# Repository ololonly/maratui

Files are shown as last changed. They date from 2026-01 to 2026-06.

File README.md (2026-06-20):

<p align="center">
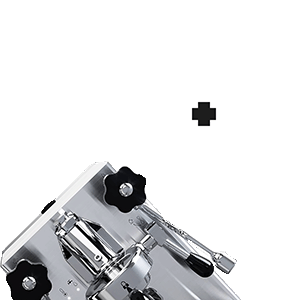
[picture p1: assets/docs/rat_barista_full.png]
MaraTUI — rat barista
    
    <br><br>
    <a href="https://github.com/ratatui/ratatui">
        
    </a>
</p>

# MaraTUI

An embedded Rust TUI application for the **Lelit Mara X** espresso machine. Runs on an **ESP32** microcontroller driving an **ILI9341 320×240 display** over SPI, reads machine telemetry over UART, and publishes events to MQTT. Includes a host simulator mode for UI development without any hardware.

## Screenshots

| Loading | Dashboard | Debug |
|---|---|---|
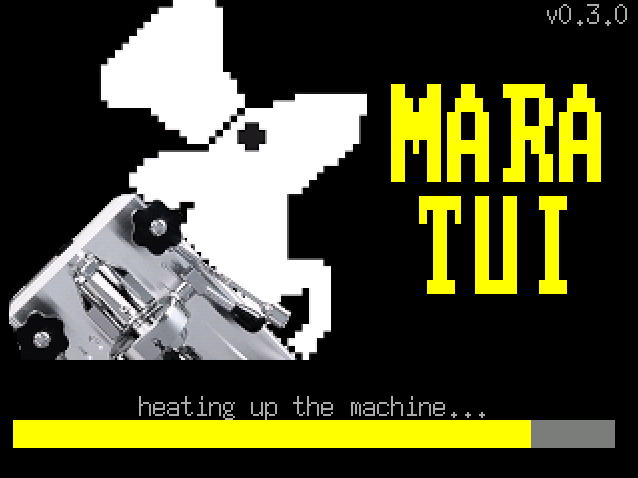
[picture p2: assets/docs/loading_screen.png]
Loading
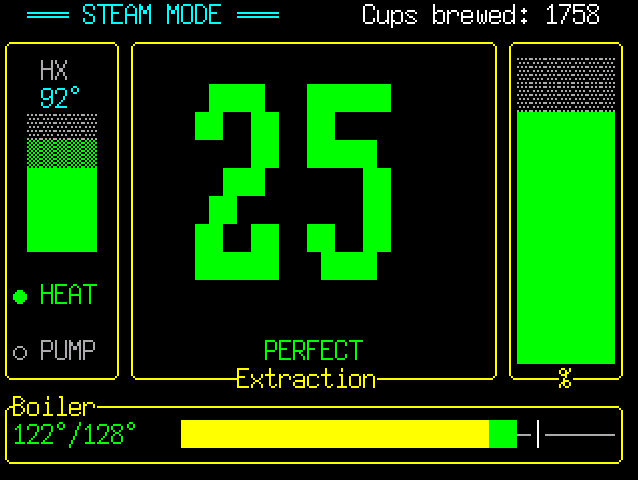
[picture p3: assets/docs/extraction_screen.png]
Dashboard
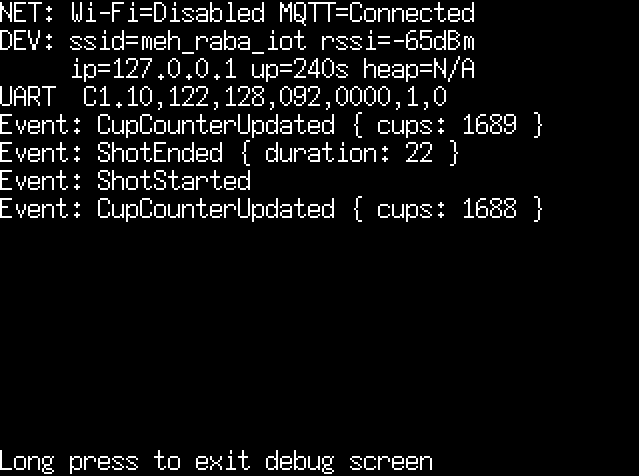
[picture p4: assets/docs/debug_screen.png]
Debug
|  |  |  |

## Screens

Navigation cycles between two main screens with a button press. The Debug screen is a hidden overlay.

### Dashboard

The primary screen. Shows all real-time machine data:

- **Mode banner** — COFFEE / STEAM / OFFLINE, color-coded
- **Boiler gauge** — current vs. target temperature with warm→ready color zones and a target marker
- **HX column** — heat-exchanger temperature with a vertical mini-gauge; ideal zone (90–95°C) is always visible
- **HEAT / PUMP indicators** — live status dots
- **Extraction timer** — large countdown in seconds, color shifts white→green→yellow as the shot progresses
- **Shot quality label** — post-extraction assessment (UNDEREXTRACTED / GOOD / PERFECT / LONG SHOT / BLONDING) shown after the pump stops
- **Cup counter** — total shots brewed, received via MQTT

### Graphs

Temperature history chart over a **5-minute rolling window** sampled at 1 Hz:

- Boiler current temperature (yellow)
- Boiler target temperature (red)
- HX temperature (blue)

### Debug (hidden overlay)

Accessible via long press. Shows Wi-Fi and MQTT connection statuses, device info (SSID, RSSI, IP, uptime, free heap), live raw UART frame with activity indicator, and the last 10 telemetry events.

## Getting Started

### Simulator

The simulator runs on your host machine using SDL2 for display emulation — no ESP32 needed.

**Prerequisites:** install SDL2 development libraries for your OS ([installation guide](https://docs.rs/crate/sdl2/latest/source/README.md)).

```bash
make sim          # auto-detects OS
```

Or use platform-specific cargo aliases:

| OS | Command |
|---|---|
| Linux | `cargo sim` |
| macOS | `cargo simmac` |
| Windows | `cargo simwin` |

**Keyboard controls:**

| Key | Action |
|---|---|
| Right / Left | Toggle Dashboard ↔ Graphs |
| D | Toggle Debug overlay |
| Up | Inject pump-on debug frame |
| Down | Inject normal debug frame |
| Space | Inject no-water debug frame |
| M | Publish manual MQTT event |

### Device (ESP32)

**Prerequisites:** Rust with the `esp` toolchain channel (pinned in `rust-toolchain.toml`).

```bash
cargo run --release
```

Uses `espflash flash --monitor` as the runner. On startup the firmware:

1. Connects to Wi-Fi using embedded credentials
2. Starts the MQTT client and subscribes to `<prefix>/cup_counter`
3. Streams telemetry to `<prefix>/telemetry` (~1 Hz)
4. Publishes events (shot start/end, water refill, mode change) to `<prefix>/events`
5. Publishes device status (IP, RSSI, uptime, heap) to `<prefix>/status`

## Configuration

Copy `.env.example` to `.env` (git-ignored) and fill in your values:

```bash
cp .env.example .env
```

| Variable | Description |
|---|---|
| `MARATUI_WIFI_SSID` / `_PASSWORD` | Wi-Fi credentials (device build only) |
| `MARATUI_MQTT_ENABLED` | Set `true` to enable MQTT publishing |
| `MARATUI_MQTT_URL` | Broker URL, e.g. `mqtt://192.168.1.x:1883` |
| `MARATUI_MQTT_CLIENT_ID` | Unique client identifier |
| `MARATUI_MQTT_TOPIC_PREFIX` | Topic namespace prefix (default: `mara`) |

> [!NOTE]
> On the ESP32 build (`device` feature), `.env` is parsed by `build.rs` and values are embedded at compile time. On the simulator (`simulator` feature), env values are read at runtime and Wi-Fi is skipped — host networking is used directly for MQTT.

> [!WARNING]
> Wi-Fi and MQTT credentials are stored as plaintext `&'static str` in the flash image. Rotate credentials if the device is shared or its firmware is distributed. See the [Security Considerations](#security-considerations) section below.

## Home Assistant Integration

Build with `--features home-assistant` to enable MQTT Discovery publishing directly from the firmware — no Node-RED or other bridge required. On every MQTT connect, retained discovery configs are published and entities appear in Home Assistant automatically.

```bash
cargo run --release --features home-assistant   # flash
make sim-ha                                      # simulator
```

See [docs/home-assistant.md](docs/home-assistant.md) for the full entity list, MQTT topic reference, and cup counter setup.

## Hardware

Target board: **ESP32 Type-C** with an external **ILI9341** 240×320 TFT display connected over SPI. There is a single physical button.

| Press | Action |
|---|---|
| Short | Toggle Dashboard ↔ Graphs |
| Short (on loading)| Toggle display backlight |
| Long | Enter / exit Debug overlay |

See [`hardware/`](hardware/) for the KiCad project, PCB renders, Gerber files, and full ESP32 pinout and display wiring.

## Security Considerations

- **Credentials in flash** — Wi-Fi and MQTT credentials are embedded at compile time and extractable from the flash image with standard tools (`strings`, `binwalk`). Rotate if the device is shared.
- **Default broker is public** — `mqtt://broker.emqx.io:1883` is a free public broker with no access control. Set a private broker with authentication before deploying.
- **No TLS** — traffic is plaintext TCP. Switch to `mqtts://` and configure a CA certificate for production use.
- **Open Wi-Fi fallback** — if `MARATUI_WIFI_PASSWORD` is empty, `AuthMethod::None` is used (no encryption). A startup `warn!` names the SSID to make this explicit.

## Roadmap

- Offline mode using NVS storage

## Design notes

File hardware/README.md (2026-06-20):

# MaraTUI PCB

Custom ESP32 controller board for the [Lelit Mara X](https://lelitcoffee.com/product/mara-x/) espresso machine.

## PCB Renders

| Front | Back |
|:-----:|:----:|
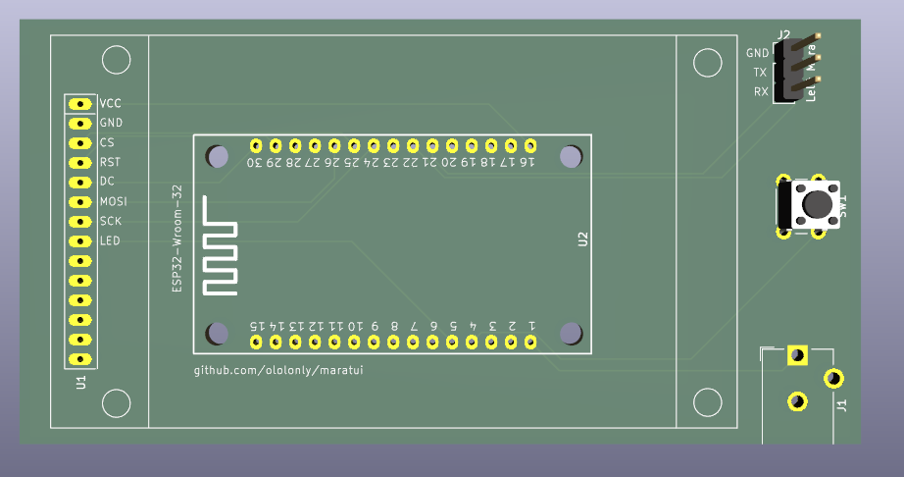
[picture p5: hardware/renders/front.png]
PCB front
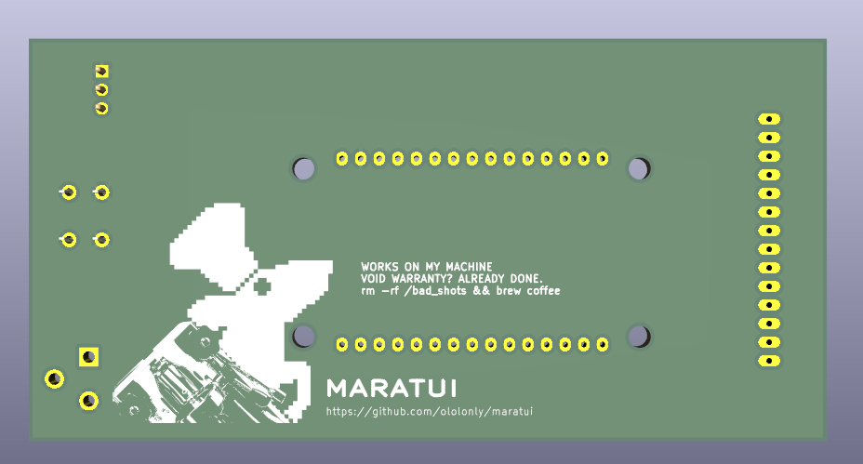
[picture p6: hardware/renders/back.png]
PCB back
|  |  |

## Components

| Ref | Part | Link |
|-----|---|---|
| U1 | ILI9341 2.8" SPI TFT with touch | [Amazon TR](https://www.amazon.com.tr/2-8in%C3%A7-SPI-Dokunmatik-Ekran-Mod%C3%BCl%C3%BC/dp/B0GWFFJBZN) |
| U2 | ESP32-WROOM-32 | [Amazon TR](https://www.amazon.com.tr/ESP32-Wroom-32-Wifi-Bluetooth-Geli%C5%9Ftirme-Kart%C4%B1/dp/B0BT7SW1LF) |
| SW1 | Tactile switch | |
| J1 | Barrel jack (power) | |
| J2 | 3-pin connector (GND + UART) | |

## Wiring

### SPI Display (ILI9341)

| Display Pin | ESP32 GPIO | Notes |
|---|---|---|
| SCK / CLK | GPIO18 | VSPI CLK |
| SDA / MOSI  | GPIO21 | VSPI MOSI |
| DC / RS | GPIO23 | Data/Command select |
| CS | GPIO19 | Chip Select |
| RST / RESET | GPIO22 | Hardware reset |
| LED / BLK | GPIO14 | Backlight (HIGH = on) |
| VCC | 3.3V | |
| GND | GND | |

### UART (Lelit Mara X telemetry)

| Function | ESP32 GPIO | Notes |
|---|---|---|
| TX | GPIO17 | UART1 TX |
| RX | GPIO16 | UART1 RX |

### Button

| Button | ESP32 GPIO | Notes |
|---|---|---|
| SW1 | GPIO12 | Internal pull-up enabled |

Button connects GPIO to **GND** via a tactile switch (active LOW, falling-edge detection).

- Short press (< 500 ms): cycle screens (Dashboard ↔ Graphs)
- Long press (≥ 500 ms): toggle Debug screen

## Custom Libraries

Non-standard components are bundled in `lib/` so the project opens without missing library errors on any machine.

| File | Description |
|---|---|
| `lib/symbols/esp32_30pin.kicad_sym` | ESP32-WROOM-32 symbol |
| `lib/symbols/tft_320x240.kicad_sym` | ILI9341 320×240 symbol |
| `lib/footprints/maratui.pretty/ESP32_30pin.kicad_mod` | ESP32 footprint |
| `lib/footprints/maratui.pretty/TFT-320x240.kicad_mod` | TFT display footprint |

## Manufacturing

Gerber files for fabrication: `gerbers/maratui-v1.zip`

Tested with JLCPCB default 2-layer settings.

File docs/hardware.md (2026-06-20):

# Hardware Wiring

Target board: **ESP32 Type-C** (generic) with external **ILI9341** 240x320 TFT display.

| ESP32 Type-C | ILI9341 Display |
|:---:|:---:|
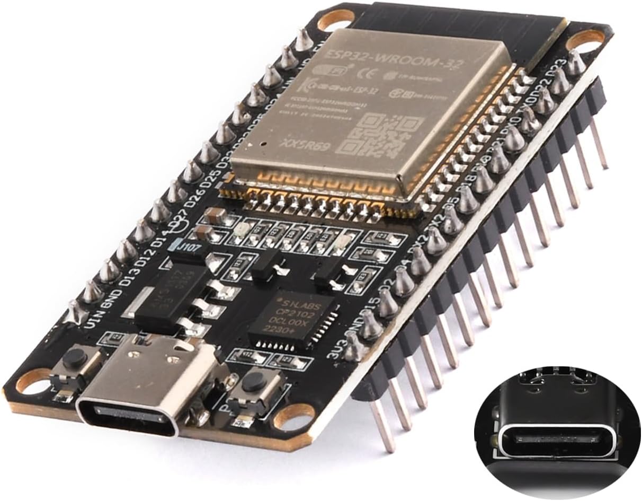
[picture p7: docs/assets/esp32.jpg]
ESP32
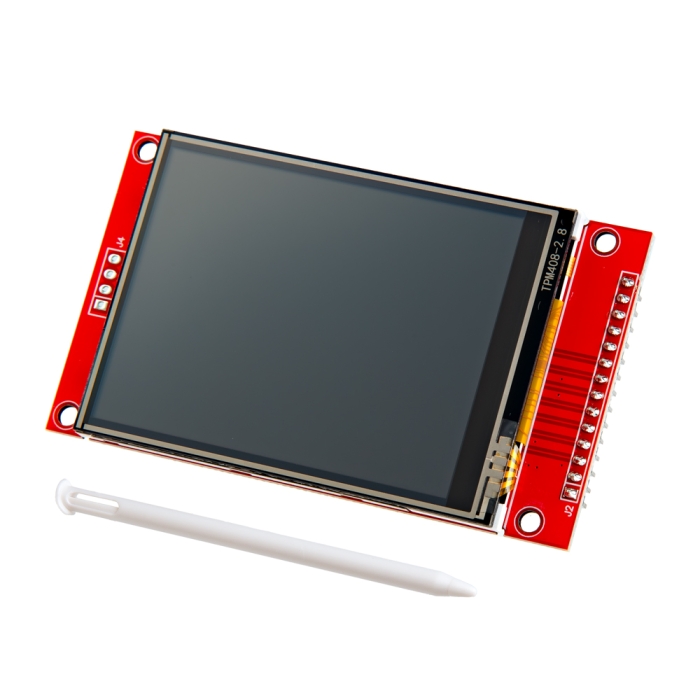
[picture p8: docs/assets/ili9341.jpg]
ILI9341
|  |  |

## Pinout

### SPI Display (ILI9341)

| Display Pin | ESP32 GPIO | Notes |
|---|---|---|
| SCK / CLK | GPIO18 | VSPI CLK |
| SDA / MOSI  | GPIO21 | VSPI MOSI |
| DC / RS | GPIO23 | Data/Command select |
| CS | GPIO19 | Chip Select |
| RST / RESET | GPIO22 | Hardware reset |
| LED / BLK | GPIO14 | Backlight (driven HIGH = on) |
| VCC | 3.3V | |
| GND | GND | |

### UART (Lelit Mara X telemetry)

| Function | ESP32 GPIO | Notes |
|---|---|---|
| TX | GPIO17 | UART1 TX |
| RX | GPIO16 | UART1 RX |

### Button

| Button | ESP32 GPIO | Notes |
|---|---|---|
| Button 1 | GPIO12 | Internal pull-up enabled |

Button connects GPIO to **GND** through a tactile switch (active LOW, NegEdge detection).
Short press (< 500 ms): toggle Dashboard ↔ Graphs. Long press (≥ 500 ms): toggle Debug screen.

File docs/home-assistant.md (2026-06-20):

# Home Assistant Integration

MaraTUI can publish Home Assistant MQTT Discovery configs directly from the firmware — no Node-RED or any other bridge required.

## Architecture

```
ESP32 (MaraTUI)
    │  UART telemetry
    │  MQTT (homeassistant/# discovery + state)
    └─► MQTT broker ──────────────────────────────► Home Assistant
                                                          │
                                                    sensors / binary sensors
                                                    auto-registered via Discovery
```

On connect, the firmware publishes retained discovery configs to `homeassistant/sensor/maratui_*/config` and `homeassistant/binary_sensor/maratui_*/config`. Home Assistant picks them up automatically — no manual YAML needed.

## Prerequisites

- MQTT broker reachable by both the ESP32 and Home Assistant (e.g. Mosquitto on the same host)
- Home Assistant with the MQTT integration enabled (Settings → Devices & Services → MQTT)

## Enabling HA Discovery

Add `--features home-assistant` to your build command:

**Flash to device:**
```bash
cargo run --release --features home-assistant
# or
make flash-ha
```

**Run the simulator:**
```bash
cargo simha          # Linux
cargo simmacHA       # macOS
make sim-ha          # auto-detects OS
```

That's it — on first MQTT connect the firmware publishes all discovery configs, and entities appear in HA within seconds.

## MQTT Topics Published by MaraTUI

### `<prefix>/telemetry` — ~1 Hz JSON frame

```json
{
  "mode": "Coffee",
  "sw": "1.10",
  "boiler_now_c": 93,
  "boiler_target_c": 94,
  "hx_now_c": 91,
  "boost_countdown_s": 0,
  "heating_on": false,
  "pump_on": false,
  "no_water_code": null
}
```

### `<prefix>/events` — on-change JSON events

| `type` | Extra fields | Description |
|---|---|---|
| `shot_started` | — | Pump just turned on |
| `shot_ended` | `duration` (int, seconds) | Pump turned off; duration of the shot |
| `shot_aborted` | `duration` (int, seconds) | Pump ran < 10 s (rinse / pre-heat kick) |
| `water_refill_needed` | `code` (int) | Water low detected |
| `water_refill_cleared` | — | Water low cleared |
| `mode_changed` | `from`, `to` (strings) | Machine mode transition |

### `<prefix>/status` — periodic device info (~30 s)

```json
{
  "uptime_s": 3600,
  "wifi_ssid": "MyNetwork",
  "wifi_rssi": -62,
  "ip": "192.168.1.42",
  "free_heap_b": 180000,
  "last_telemetry_age_s": 1
}
```

The topic prefix defaults to `mara` and is configured via `MARATUI_MQTT_TOPIC_PREFIX` in `.env`.

## Home Assistant Entities

All entities appear under a single device named **Lelit Mara X**.

### Sensors

| Entity | Unit | Notes |
|---|---|---|
| Mode | — | Operating mode |
| Firmware Version | — | Diagnostic |
| Boiler Temperature | °C | `device_class: temperature` |
| Boiler Target | °C | `device_class: temperature` |
| HX Temperature | °C | `device_class: temperature` |
| Last Extraction Duration | s | Retained; updated on shot end |
| Extraction Timer | s | Live counter during shot |
| Time Since Last Shot | min | Minutes since pump last stopped |
| Cup Counter | — | See cup counter setup below |
| Uptime | min | Diagnostic |
| Wi-Fi RSSI | dBm | Diagnostic |
| Wi-Fi SSID | — | Diagnostic |
| IP Address | — | Diagnostic |
| Free Heap | kB | Diagnostic |
| Telemetry Age | s | Diagnostic |

### Binary Sensors

| Entity | Notes |
|---|---|
| Heating | `device_class: heat` |
| Pump Active | On while shot is in progress |
| Water Level Low | `device_class: problem` |

## Cup Counter Setup

The cup counter requires a short one-time setup in Home Assistant. The counter value is stored as an HA helper and published back to the broker so the MaraTUI display stays in sync.

### 1. Create a Counter helper

Settings → Devices & Services → Helpers → **+ Create helper** → **Counter**

- Name: `Mara Shots`
- Entity ID: `counter.coffee_counter` (default)
- Initial value: your current count (or 0)

### 2. Import the automation

Settings → Automations → **+ Create automation** → ⋮ menu → **Edit in YAML**

Paste the contents of `docs/ha-automation.yaml`, save, and enable.

The automation triggers on `mara/events` when `type == shot_ended` and `duration > 20 s`, increments the helper, and publishes the new value to `mara/cup_counter` (retained) so both the HA sensor and the ESP32 display update.

### Cup counter flow

```
MaraTUI → mara/events {"type":"shot_ended","duration":35}
               ↓
         HA automation (ha-automation.yaml)
         duration > 20 s → counter.increment(counter.coffee_counter)
                         → mqtt.publish(mara/cup_counter, retained)
               ↓
         ESP32 subscribes to mara/cup_counter → display updates
         HA sensor maratui_cup_counter reads mara/cup_counter → HA updates
```

## Troubleshooting

**Entities don't appear in HA**
- Check that the MQTT integration is enabled (Settings → Devices & Services → MQTT).
- Confirm the broker MaraTUI connects to is the same one HA uses.
- Subscribe to `homeassistant/#` with `mosquitto_sub -t 'homeassistant/#' -v` to verify discovery configs are arriving.
- Power-cycle or reconnect the ESP32 — discovery configs are re-sent on every MQTT connect.

**Values don't update**
- Confirm the ESP32 is connected to Wi-Fi and MQTT (`MARATUI_MQTT_ENABLED=true` in `.env`).
- Check the MaraTUI Debug screen for UART activity and connection status.
- Subscribe to `mara/#` to see raw messages from the device.

**Topic mismatch**
- If you set `MARATUI_MQTT_TOPIC_PREFIX` to something other than `mara`, update the topics in `docs/ha-automation.yaml` accordingly.

**Cup counter not incrementing**
- Verify the automation is enabled and the trigger topic matches your prefix.
- Check HA automation traces (Settings → Automations → Mara Shot Counter → ⋮ → Traces).

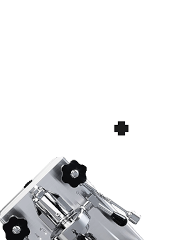
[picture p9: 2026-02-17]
assets/rat_barista.png

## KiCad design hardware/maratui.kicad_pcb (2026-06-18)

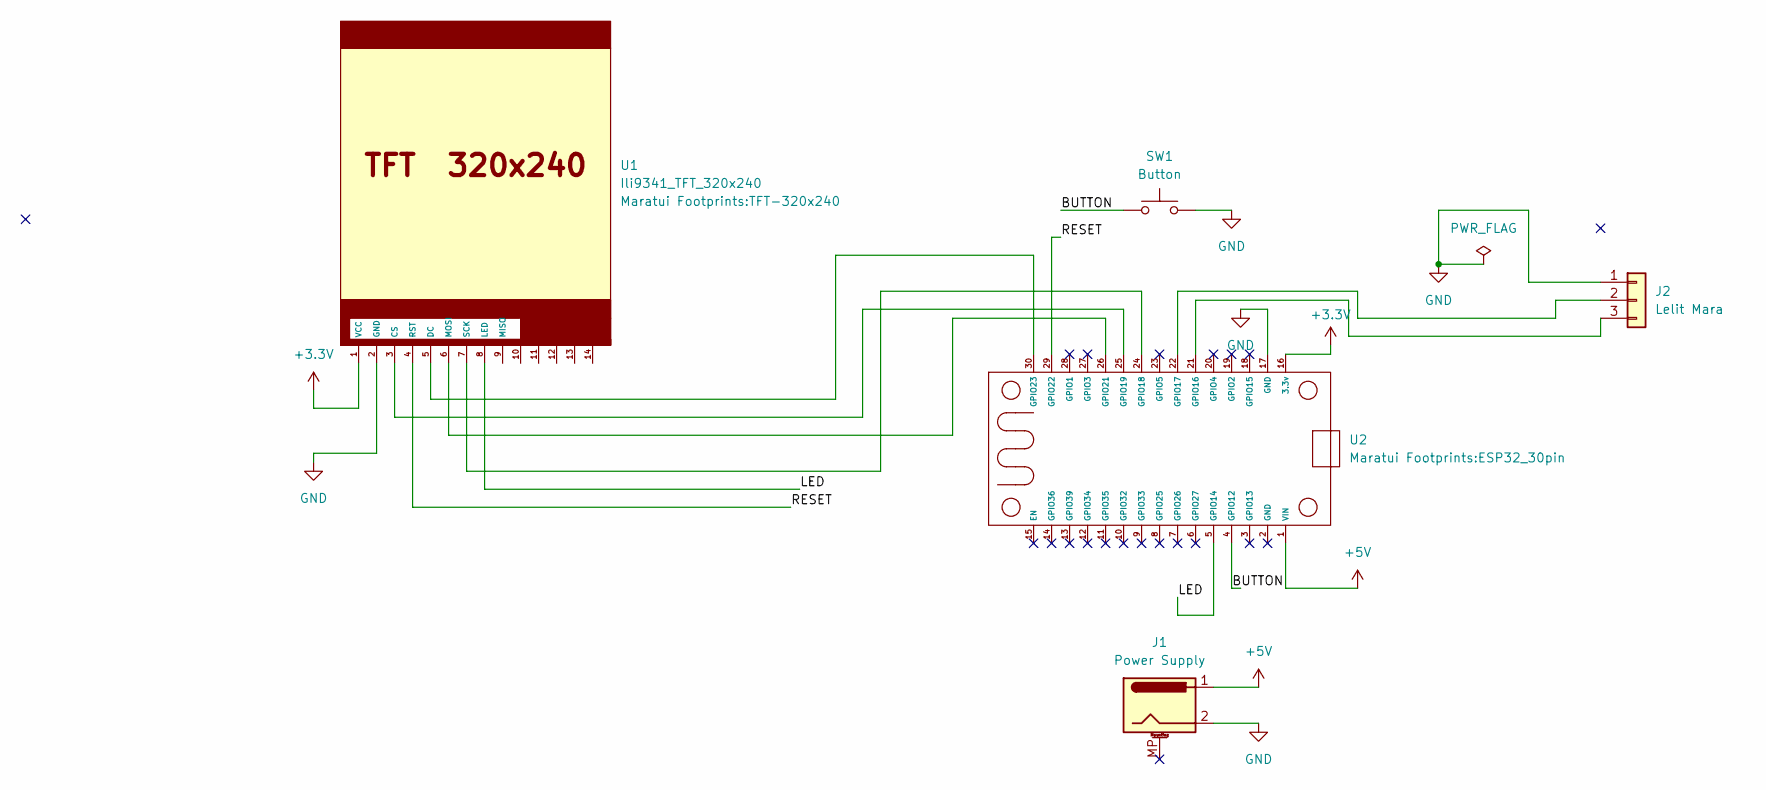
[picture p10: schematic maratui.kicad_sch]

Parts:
J1: Power Supply; BarrelJack_CUI_PJ-102AH_Horizontal
J2: Lelit Mara; PinHeader_1x03_P2.54mm_Vertical
SW1: Button; SW_PUSH_6mm
U1: Ili9341_TFT_320x240; TFT-320x240
U2: ESP32_30pin

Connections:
+3.3V: U1.1 (VCC), U2.16 (3.3v)
+5V: J1.1, U2.1 (VIN)
/BUTTON: SW1.1, U2.4 (GPIO12)
/LED: U1.8 (LED), U2.5 (GPIO14)
/RESET: U1.4 (RST), U2.29 (GPIO22)
GND: J1.2, J2.1, SW1.2, U1.2 (GND), U2.17 (GND)
unnamed: J2.2, U2.22 (GPIO17)
unnamed: J2.3, U2.21 (GPIO16)
unnamed: U1.3 (CS), U2.25 (GPIO19)
unnamed: U1.5 (DC), U2.30 (GPIO23)
unnamed: U1.6 (MOSI), U2.26 (GPIO21)
unnamed: U1.7 (SCK), U2.24 (GPIO18)

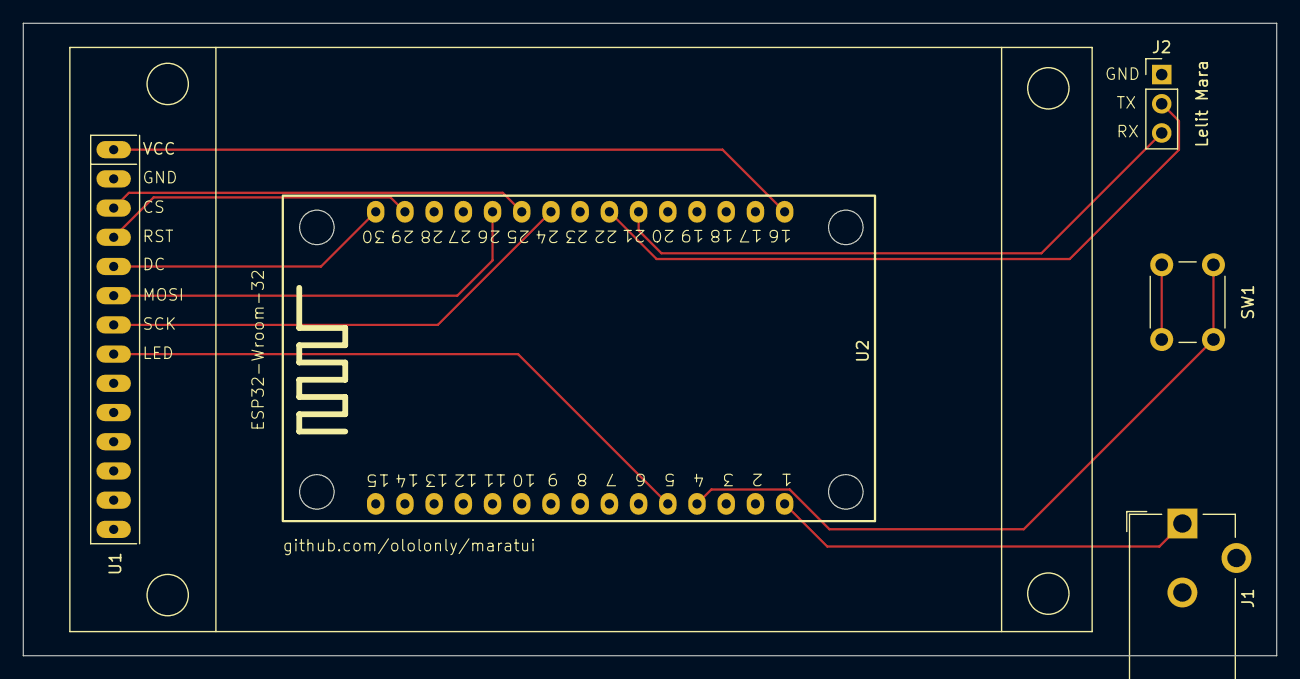
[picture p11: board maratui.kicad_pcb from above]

Board: 2 copper layers, 109.0 x 55.0 mm, 5 parts (0 on the bottom side), 12 nets.

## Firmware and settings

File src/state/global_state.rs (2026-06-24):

use crate::screens::Screen;
use crate::telemetry::MachineState;
use std::{
    collections::VecDeque,
    time::{Duration, Instant},
};

// TODO: if the device is powered directly from the espresso machine, the backlight
// timeout is unnecessary — consider removing BACKLIGHT_TIMEOUT and backlight_should_be_on entirely.
pub const BACKLIGHT_TIMEOUT: Duration = Duration::from_secs(10);

/// How long telemetry may be absent before the machine is considered offline.
///
/// Once this elapses with no UART frame, the UI falls back to the waiting screen and
/// the next frame to arrive starts a fresh session (terminal + graph buffers cleared).
pub const MACHINE_OFFLINE_TIMEOUT: Duration = Duration::from_secs(30);

#[derive(Clone, Debug, Default, PartialEq, Eq)]
pub enum ConnectionStatus {
    Disabled,
    #[default]
    Disconnected,
    Connecting,
    Connected,
    Error(String),
}

#[derive(Clone, Debug)]
pub struct MqttOutboundMessage {
    /// Topic suffix (combined with prefix by publish_mqtt_message) unless `absolute` is true.
    pub topic_suffix: String,
    pub payload: String,
    /// When `true`, the broker should store a retained copy of this message.
    pub retain: bool,
    /// When `true`, `topic_suffix` is used as-is (bypasses prefix construction).
    pub absolute: bool,
}

/// State of the coffee extraction process
#[derive(Clone, Debug, PartialEq, Eq)]
pub enum ExtractionState {
    /// Pump is not running, no extraction in progress
    Idle {
        /// Duration of the last completed extraction
        last_extraction_duration: Option<Duration>,
    },
    /// Pump is running, extraction in progress
    Extracting { started_at: Instant },
}

impl Default for ExtractionState {
    fn default() -> Self {
        Self::Idle {
            last_extraction_duration: None,
        }
    }
}

impl ExtractionState {
    /// Get the duration of the current extraction (if in progress)
    pub fn elapsed(&self) -> Option<Duration> {
        match self {
            ExtractionState::Extracting { started_at } => Some(started_at.elapsed()),
            ExtractionState::Idle { .. } => None,
        }
    }

    /// Check if extraction is currently in progress
    pub fn is_extracting(&self) -> bool {
        matches!(self, ExtractionState::Extracting { .. })
    }

    /// Get the duration of the last completed extraction
    pub fn last_extraction_duration(&self) -> Option<Duration> {
        match self {
            ExtractionState::Idle {
                last_extraction_duration,
            } => *last_extraction_duration,
            ExtractionState::Extracting { .. } => None,
        }
    }
}

/// Board metadata published to MQTT and shown on the Debug screen
#[derive(Clone, Debug, Default, PartialEq, Eq)]
pub struct DeviceInfo {
    pub wifi_ssid: String,
    pub wifi_rssi: Option<i32>,
    pub ip: Option<String>,
    pub uptime_s: u64,
    pub free_heap_b: Option<u32>,
    /// Seconds since the last UART telemetry frame was received
    pub last_telemetry_age_s: Option<u64>,
}

/// Application errors
#[derive(Clone, Debug, PartialEq, Eq)]
pub enum AppError {
    /// Water refill is needed
    WaterRefillNeeded { code: u16 },
    /// Machine is offline
    MachineOffline,
}

impl std::fmt::Display for AppError {
    fn fmt(&self, f: &mut std::fmt::Formatter<'_>) -> std::fmt::Result {
        match self {
            AppError::WaterRefillNeeded { code } => {
                write!(f, "Water refill needed (code: {})", code)
            }
            AppError::MachineOffline => write!(f, "Machine is offline"),
        }
    }
}

/// Global application state
/// Single point of state management for the entire application
#[derive(Debug)]
pub struct GlobalAppState {
    /// Currently displayed screen
    pub current_screen: Screen,
    /// State of the extraction process
    pub extraction_state: ExtractionState,
    /// Machine state (mode, temperatures, pump, etc.)
    pub machine_state: MachineState,
    pub events_log: VecDeque<String>,
    pub wifi_status: ConnectionStatus,
    pub mqtt_status: ConnectionStatus,
    pub cup_counter: Option<u64>,
    pub outbound_mqtt: VecDeque<MqttOutboundMessage>,
    /// Current error (if any)
    pub error: Option<AppError>,
    /// Screen to return to when toggling out of Debug
    pub screen_before_debug: Option<Screen>,
    /// Backlight toggle during the loading phase (short press on/off); ignored after first UART frame
    pub backlight_on: bool,
    /// Last time UART telemetry or a button press was received (for backlight timeout)
    pub last_activity_at: Option<Instant>,
    /// Last time a UART telemetry frame was received (for Debug screen activity marker)
    pub last_uart_frame_at: Option<Instant>,
    /// Time when the last shot ended (pump turned off after a valid extraction)
    pub last_shot_ended_at: Option<Instant>,
    /// MQTT topic prefix (e.g. "mara"), mirrored from AppConfig for use in HA state topics
    pub mqtt_topic_prefix: String,
    /// Board metadata (WiFi RSSI, IP, uptime, free heap)
    pub device_info: DeviceInfo,
    /// Current boot loading stage; `None` before first stage fires, frozen at 100% while waiting for machine
    pub loading_status: Option<(&'static str, u8)>,
    /// Set by the state machine to ask the render loop for a full `terminal.clear()`
    /// (new session, Debug toggle). Drained once per frame via `take_redraw_request`.
    pub needs_terminal_clear: bool,
}

impl Default for GlobalAppState {
    fn default() -> Self {
        Self {
            current_screen: Screen::default(),
            extraction_state: ExtractionState::default(),
            machine_state: MachineState::default(),
            events_log: VecDeque::with_capacity(10),
            wifi_status: ConnectionStatus::default(),
            mqtt_status: ConnectionStatus::default(),
            cup_counter: None,
            outbound_mqtt: VecDeque::with_capacity(32),
            error: None,
            screen_before_debug: None,
            backlight_on: true,
            last_activity_at: None,
            last_uart_frame_at: None,
            last_shot_ended_at: None,
            mqtt_topic_prefix: "mara".to_string(),
            device_info: DeviceInfo::default(),
            loading_status: None,
            needs_terminal_clear: false,
        }
    }
}
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

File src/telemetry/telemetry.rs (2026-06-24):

// src/telemetry.rs
use std::{collections::VecDeque, time::Instant};
use strum::Display;

#[derive(Debug, Display, Default, Clone, Copy, PartialEq, Eq)]
pub enum MachineMode {
    #[strum(to_string = "Coffee")]
    Coffee, // '-' | '+'
    #[strum(to_string = "Steam")]
    SteamS, // 'S'
    #[strum(to_string = "Steam")]
    SteamV, // 'V'
    #[strum(to_string = "Steam")]
    SteamC, // 'C' (as you described)
    #[default]
    Offline, // 'X'
    Unknown(char),
}

impl MachineMode {
    pub fn from_char(c: char) -> Self {
        match c {
            '-' | '+' => MachineMode::Coffee,
            'S' => MachineMode::SteamS,
            'V' => MachineMode::SteamV,
            'C' => MachineMode::SteamC,
            'X' => MachineMode::Offline,
            other => MachineMode::Unknown(other),
        }
    }
}

#[derive(Debug, Default, Clone, PartialEq, Eq)]
pub struct TelemetryFrame {
    pub raw_string: String,
    pub mode: MachineMode,
    pub sw_version: String,           // e.g. "1.10"
    pub boiler_now_c: u16,            // e.g. 37
    pub boiler_target_c: Option<u16>, // Some(138) or None if Lxx
    pub no_water_code: Option<u16>,   // Some(65) if "L65"
    pub hx_now_c: u16,                // e.g. 35
    pub boost_countdown_s: u16,       // e.g. 0000 -> 0
    pub heating_on: bool,             // "1"/"0"
    pub pump_on: bool,                // "1"/"0"
}

impl TelemetryFrame {
    pub fn debug_frame() -> Self {
        Self {
            raw_string: "C1.10,122,128,092,0000,1,0".to_string(),
            mode: MachineMode::SteamC,
            sw_version: "1.10".to_string(),
            boiler_now_c: 122,
            boiler_target_c: Some(128),
            hx_now_c: 92,
            boost_countdown_s: 0,
            heating_on: true,
            pump_on: false,
            no_water_code: None,
        }
    }

    pub fn debug_pump_on_frame() -> Self {
        Self {
            raw_string: "C1.10,120,138,090,0000,1,1".to_string(),
            mode: MachineMode::SteamC,
            sw_version: "1.10".to_string(),
            boiler_now_c: 120,
            boiler_target_c: Some(138),
            hx_now_c: 90,
            boost_countdown_s: 0,
            heating_on: true,
            pump_on: true,
            no_water_code: None,
        }
    }

    pub fn debug_no_water_frame() -> Self {
        Self {
            raw_string: "C1.10,122,L65,085,0000,0,0".to_string(),
            mode: MachineMode::Coffee,
            sw_version: "1.10".to_string(),
            boiler_now_c: 122,
            boiler_target_c: None,
            hx_now_c: 85,
            boost_countdown_s: 0,
            heating_on: false,
            pump_on: false,
            no_water_code: Some(65),
        }
    }
}

#[derive(Debug, Clone, PartialEq, Eq)]
pub enum ParseError {
    Empty,
    BadPrefix,
    WrongFieldCount { got: usize, expected: usize },
    BadNumber { field: &'static str, value: String },
    BadBool { field: &'static str, value: String },
}

/// Parses UART line format:
/// <Mode><Version>,<boiler_now>,<boiler_target_or_Lxx>,<hx_now>,<boost>,<heating>,<pump>
/// Examples:
/// - C1.10,037,138,035,0000,0,1
/// - C1.10,037,L65,035,0000,0,0   (no water)
/// - +1.10,089,P75,067,0000,0,0   (P-prefix seen at cold startup in xmode_coffee; semantics TBD)
pub fn parse_uart_line(line: &str) -> Result<TelemetryFrame, ParseError> {
    let s = line.trim();
    if s.is_empty() {
        return Err(ParseError::Empty);
    }

    // First char is the machine mode
    let mut chars = s.chars();
    let mode_char = chars.next().ok_or(ParseError::Empty)?;
    let mode = MachineMode::from_char(mode_char);

    // Until the first comma is a software version (e.g. "1.10")
    let rest = &s[mode_char.len_utf8()..];
    let comma_pos = rest.find(',').ok_or(ParseError::BadPrefix)?;
    let sw_version = rest[..comma_pos].to_string();

    let after = &rest[comma_pos + 1..];
    let parts: Vec<&str> = after.split(',').collect();

    // Expected 6 fields after version:
    // boiler_now, boiler_target_or_Lxx, hx_now, boost, heating, pump
    if parts.len() != 6 {
        return Err(ParseError::WrongFieldCount {
            got: parts.len(),
            expected: 6,
        });
    }

    let boiler_now_c = parse_u16(parts[0], "boiler_now_c")?;

    let (boiler_target_c, no_water_code) = {
        let t = parts[1].trim();
        if let Some(code) = t.strip_prefix('L') {
            let code = parse_u16(code, "no_water_code")?;
            (None, Some(code))
        } else if t.starts_with(|c: char| c.is_ascii_alphabetic()) {
            // Non-numeric prefix other than 'L' — observed as "Pxx" at cold startup in xmode_coffee.
            // Exact semantics are still under investigation (possibly power-up / initial-heating phase).
            // Accepted without error; boiler_target treated as unknown until the frame normalises.
            (None, None)
        } else {
            let target = parse_u16(t, "boiler_target_c")?;
            (Some(target), None)
        }
    };

    let hx_now_c = parse_u16(parts[2], "hx_now_c")?;
    let boost_countdown_s = parse_u16(parts[3], "boost_countdown_s")?;
    let heating_on = parse_bool01(parts[4], "heating_on")?;
    let pump_on = parse_bool01(parts[5], "pump_on")?;

    let raw_string = line.to_string();

    Ok(TelemetryFrame {
        raw_string,
        mode,
        sw_version,
        boiler_now_c,
        boiler_target_c,
        no_water_code,
        hx_now_c,
        boost_countdown_s,
        heating_on,
        pump_on,
    })
}

fn parse_u16(s: &str, field: &'static str) -> Result<u16, ParseError> {
    let t = s.trim();
    t.parse::<u16>().map_err(|_| ParseError::BadNumber {
        field,
        value: t.to_string(),
    })
}

fn parse_bool01(s: &str, field: &'static str) -> Result<bool, ParseError> {
    match s.trim() {
        "0" => Ok(false),
        "1" => Ok(true),
        other => Err(ParseError::BadBool {
            field,
            value: other.to_string(),
        }),
    }
}

const MIN_SHOT_SECS: u64 = 15;

/// High-level events derived from telemetry stream.
/// These are perfect triggers for MQTT "events" topics and for UI notifications.
#[derive(Debug, Clone, PartialEq, Eq)]
pub enum AppEvent {
    /// Pump transitioned from OFF -> ON.
    ShotStarted,

    /// Pump transitioned from ON -> OFF, with total ON duration.
    ShotEnded { duration: u64 },

    /// Pump ran for less than MIN_SHOT_SECS (rinsing / post-heat pump kick).
    ShotAborted { duration: u64 },

    /// No-water condition appeared (None -> Some(code)) or code changed.
    WaterRefillNeeded { code: u16 },

    /// No-water condition cleared (Some -> None).
    WaterRefillCleared,

    /// Mode changed (e.g. Coffee -> Steam, etc.).
    ModeChanged { from: MachineMode, to: MachineMode },
}
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

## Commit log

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2026-01-23 feat(logging): add logging support and improve UART handling
    - Integrated `log` crate for enhanced logging throughout the application.
    - Updated UART initialization to use UART1 instead of UART2, with improved error handling and logging.
    - Refactored `UartReader` to include non-blocking read checks and better buffer management.
    - Enhanced telemetry update logic in `run_app` to reduce load and prevent watchdog timeouts.
    [setup.rs, uart_reader.rs]
2026-01-23 refactor(run_app): simplify UI drawing logic and remove frame counter condition
    - Removed the conditional frame drawing to allow the UI to be drawn on every iteration, improving responsiveness.
    - Maintained a delay to prevent watchdog timeouts and ensure other tasks can run effectively.
    [setup.rs]
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2026-01-28 trying to impement ili9341 display support. extra code commented. just trying to run w/o alloc error
    [setup.rs]
2026-01-28 refactor: update rat and screen modules to use ratatui directly
    - Replaced mousefood crate imports with direct imports from ratatui for Frame, Buffer, Layout, and other components.
    - Added a new constructor method for the Rat struct.
    - Updated the rendering logic to utilize the new Line type from ratatui for text handling.
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2026-01-30 feat(build): enhance build script for ESP32 and add feature flags
    - Updated `build.rs` to check for simulator and device features, providing clearer error messages for simulator usage.
    - Modified `Cargo.toml` to include feature flags for device and simulator builds, improving build flexibility.
    - Updated dependencies in `Cargo.lock` to include new packages and versions, ensuring compatibility with the latest features.
    [setup.rs]
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2026-02-02 fix(simulator): use debug telemetry frame on startup
    [setup.rs]
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2026-02-03 refactor(state): migrate to centralized state management with FSM
    Replace distributed state management with a centralized GlobalAppState and
    AppStateMachine. Move brew timer logic into extraction state tracking within
    the state machine. Update all screen renderers to accept state as a parameter
    instead of managing their own state.
    - Remove BrewTimer struct and integrate timing into ExtractionState
    - Create new state module with GlobalAppState and AppStateMachine
    - Update Board trait to pass GlobalAppState to render methods
    - Simplify screen components (Dashboard, Debug, Graphs, Rat) to stateless
    renderers
    - Refactor telemetry event handling to work with centralized state
    - Update simulato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
    [app.rs, debug.rs, fsm.rs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]
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2026-02-09 feat(state): add event log and frame ownership
    Move latest telemetry frame ownership into `machine_state` and add a
    bounded `events_log` to global app state for recent FSM activity.
    Update dashboard and debug screens to read from `machine_state.last_frame`,
    render an extraction timer block, and show UART plus recent events.
    Make UART parsing resilient by handling parse errors without panicking,
    and align telemetry debug frames/defaults with `no_water_code: None`.
    BREAKING CHANGE: remove `GlobalAppState.last_telemetry`; use
    `GlobalAppState.machine_state.last_frame` instead
    [debug.rs, fsm.rs, global_state.rs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]
2026-02-09 feat(ui): show no-water status in simulator
    Add a dedicated debug telemetry frame for the no-water condition and
    map it to the Space key in the simulator so the state can be exercised
    interactively.
    Update the rat status panel to display a context-aware message when a
    water refill error is present, while keeping the default coffee prompt.
    Fix event log trimming to drop the oldest entry instead of the newest
    one when the log exceeds its size limit.
    [fsm.rs, telemetry.rs]
2026-02-10 build(deps): bump mousefood to 0.4.0
    update the mousefood crate version and align rat screen code with
    current usage by removing unused text imports and icon area binding
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2026-02-11 feat(ui): render rat image directly on display
    replace the ratatui qoi widget path with embedded-graphics image
    rendering from a raw rgb565 asset on the display backend. call image
    rendering in both hardware and simulator loops, and clear the terminal
    on button-driven screen changes to prevent stale artifacts.
    remove the tinyqoi dependency and delete the qoi widget module.
    BREAKING CHANGE: MaraUiApp now requires a render_image method in trait
    implementations
    [app.rs, setup.rs]
2026-02-11 fix: move ifeq directives to top level in Makefile
    ifeq/else/endif are Make directives, not shell commands — they must
    not be indented as recipe lines. Use a variable instead.
    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
2026-02-11 fix(setup): use half-duplex SPI for ili9341
    Set the SPI device config to half-duplex and use an explicit
    Hertz baudrate value before converting into the driver config.
    This aligns setup with the display bus communication mode.
    [setup.rs]
2026-02-11 feat(ui): show thirsty rat on water refill error
    Render a dedicated thirsty rat sprite when the app state reports
    `WaterRefillNeeded` so the dashboard communicates the condition
    visually.
    Add the new thirsty image assets and keep the default barista rat for
    all other states.
    [app.rs]
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2026-02-11 feat(ui): plot live boiler and hx temperatures
    replace graph demo data with telemetry-backed time series for current
    boiler, target boiler, and hx temperatures. add rolling buffers to
    machine state and update them on each telemetry frame to keep roughly
    the last 5 minutes of data for charting.
    update chart axes and legend placement to better match the new live
    temperature ranges and timeline labels.
    [fsm.rs, telemetry.rs]
2026-02-11 feat(ui): add shortcut to open debug screen
    Introduce a dedicated DebugScreen app event and handle it in the
    state machine so pressing both buttons jumps directly to the debug
    screen.
    Update screen navigation to exclude Debug from normal next/previous
    rotation, and add a simulator keybinding (`D`) to trigger the same
    behavior for easier testing.
    [fsm.rs, setup.rs]
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2026-02-16 fix(mqtt): wait for broker connect before subscribe
    Delay topic subscription until a Connected event is received to avoid
    subscribing before the client session is ready.
    Also configure the STA netif with a DHCP hostname (`maratui`) by
    wrapping Wi-Fi with explicit netif configuration.
    [setup.rs]
2026-02-16 fix(ui): update temperature chart labels
    Rename the chart title to "Temperatures" and remove the y-axis
    title to avoid redundant labeling in the graph UI.
2026-02-17 feat(ui): add startup loading screen and new assets
    Display a full-screen loading image during hardware setup and clear the
    screen before entering the main loop to avoid stale frames.
    Update barista image assets, switch the README preview to the new full
    artwork, and move the in-app barista render to the top to fit the new
    image composition.
    [app.rs, setup.rs]
2026-02-17 fix(ui): clear display via terminal backend
    Ensure cleanup uses the same display instance managed by the
    terminal before entering the main loop
    [setup.rs]
2026-03-03 fix(hardware): align esp32 pin mapping and io setup
    [setup.rs]
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2026-04-27 feat(ui): add auto-return to previous screen after extraction with backlight timeout
    Implement automatic screen navigation and backlight management based on user activity:
    - Auto-switch to Dashboard when extraction starts, saving the previous screen
    - Auto-return to saved screen 5 seconds after extraction ends
    - Manual navigation during cooldown cancels the scheduled return
    - Backlight turns off after 10 seconds of inactivity (no telemetry or button presses)
    - Track activity timestamps for both telemetry updates and button presses
    - Clear terminal when transitioning away from Main screen to prevent artifacts
    - Fix shot duration display from milliseconds to seconds
    Add new trait methods to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
    [app.rs, fsm.rs, global_state.rs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]
2026-04-27 refactor(ui): redesign dashboard with improved layout and visual feedback
    - Reorganize layout into banner, content columns, and bottom gauge
    - Add horizontal boiler temperature gauge with color-coded status
    - Add vertical shot progress gauge with time-based quality indicators
    - Add mode-specific banner with color coding (coffee/steam/offline)
    - Add real-time status indicators for heating and pump
    - Implement post-shot quality labels (too short, perfect, etc.)
    - Use progressive color feedback during extraction (white → green → yellow)
    - Simplify information display with better use of space
    - Remove redundant blocks and improve visual hierarchy
2026-04-27 refactor(ui): replace boiler gauge with custom temperature bar and refine shot quality feedback
    Replace the generic Gauge widget with a custom temperature bar featuring:
    - Absolute temperature scale (0-150°C)
    - Color zones: yellow (warming) → green (ready at 90%)
    - Target temperature marker
    - Compact label format showing current/target temps
    Refine extraction timer quality assessment:
    - Adjust shot timing sweet spot to 25-27s for "PERFECT"
    - Expand quality labels: "FAST FLOW", "GOOD", "LONG SHOT", "BLONDING"
    - Update live extraction green zone to 20-27s
    - Pin post-shot assessment label to bottom of timer block
    Simplify layout:
    - Switch shot gauge to rule-of-thirds (1:3:1) proportional l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
2026-04-27 feat(ui): add connecting screen and block navigation before telemetry
    Add a new Connecting screen that displays until the first UART telemetry
    frame arrives. Block all navigation (except to Debug screen) until
    telemetry is received to prevent rendering errors from missing data.
    Changes include:
    - New Connecting screen module and render logic
    - Navigation blocking in button handler until first frame
    - Debug screen toggle functionality to return to previous screen
    - Dashboard early return when telemetry unavailable
    - Tests for blocked navigation and debug screen toggling
    [app.rs, fsm.rs, global_state.rs]
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2026-05-04 feat(mqtt): add real-time MQTT connection status monitoring
    Implement bidirectional status channel to track MQTT connection state changes dynamically. Both hardware and simulator setups now receive ConnAck/Disconnected events and update UI accordingly. Prevent publishing messages when disconnected and defer screen return during extraction to Dashboard or Debug screens.
    [fsm.rs, setup.rs]
2026-05-04 ci: add GitHub Actions pipeline and fix ShotStarted screen-guard bug
    - Add .github/workflows/ci.yml with three jobs: test, clippy, fmt.
    Tests run with --features simulator on x86_64-unknown-linux-gnu using
    stable Rust (overriding the esp rust-toolchain.toml via RUSTUP_TOOLCHAIN).
    SDL2 is installed as a system dependency for the simulator feature.
    Cargo registry and build artifacts are cached by Cargo.lock hash.
    - Fix logical bug in AppStateMachine::handle_event(ShotStarted): the guard
    condition used || instead of && so it was always true (tautology), causing
    screen_before_extraction to be saved even when already on Dashboard or Debug.
    The test test_shot_started_from_dashboard_d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
    [fsm.rs]
2026-05-04 fix(ci): resolve all Clippy warnings and formatting errors
    Fixes all 7 Clippy warnings that caused CI to fail under -D warnings,
    and applies rustfmt to the three files that were out of format.
    Clippy fixes:
    - global_state.rs: replace manual Default impl with #[derive(Default)] + #[default]
    - screen.rs: simplify redundant guard Some(i) if i == 0 → Some(0)
    - telemetry/mod.rs: allow module_inception (intentional re-export pattern)
    - telemetry.rs: collapse nested if-let + if into a single if-let && guard
    - telemetry.rs: remove redundant as u64 cast (as_secs() already returns u64)
    - setup_simulator.rs: collapse nested if into a single if with && conditions
    - state/fsm.rs: collapse nested if-le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
    [fsm.rs, global_state.rs, telemetry.rs]
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2026-05-06 refactor: remove Clone trait from GlobalAppState and MachineState
    Removes unnecessary Clone derivation from GlobalAppState and MachineState
    to prevent accidental heap allocations. Updates dashboard.rs to use as_ref()
    instead of clone() for last_frame access, and removes redundant event
    cloning in FSM event processing.
    This eliminates silent copying of ~7KB VecDeque data structures and
    improves overall memory efficiency.
    [fsm.rs, global_state.rs, telemetry.rs]
2026-05-06 fix(telemetry): remove unused on field from MachineState
    The on field was initialized to false and never written after that.
    Actual pump state is always read from TelemetryFrame.pump_on.
    Also updates CLAUDE.md to remove this from known bugs list.
    [telemetry.rs]
2026-05-06 fix(logging): replace eprintln with log::error in FSM error handler
    Changes eprintln! to log::error! in the ErrorOccurred event handler
    for consistency with the rest of the codebase. On ESP32 targets,
    eprintln! routes to a different sink than the ESP log system.
    Updates CLAUDE.md to reflect this bug fix by removing the resolved
    issue from the known bugs list.
    [fsm.rs]
2026-05-06 fix(button): remove 2s upper limit for long press detection
    Previously, button presses longer than 2000ms were silently ignored,
    creating an undocumented "veto zone". Now any press >= 500ms is
    classified as a long press, eliminating the confusing silent drop.
    Also removes dead code (AppConfig::telemetry_topic) and fixes
    is_telemetry_event() to correctly exclude infrastructure events
    (WifiStatusChanged, MqttStatusChanged, etc.) from the on-screen
    telemetry log. Test coverage added to verify correct classification.
2026-05-06 feat(config): add startup warnings for insecure MQTT and Wi-Fi configurations
    Add warn_insecure() method that logs warnings on startup when:
    - Default public MQTT broker (broker.emqx.io) is detected, exposing telemetry
    - MQTT credentials are sent over plaintext connections (mqtt://, tcp://, ws://)
    - Wi-Fi password is empty, connecting to open networks without encryption
    These warnings make security-sensitive configuration choices explicit in logs
    without blocking functionality for intentional open-network deployments.
    [setup.rs]
2026-05-06 fix(ci): resolve Clippy needless_borrow and rustfmt formatting issues
    - dashboard.rs: remove redundant & before t_frame (as_ref() already returns &TelemetryFrame)
    - config.rs: remove extra blank line before closing brace
    - app_events.rs: wrap long assert! lines per rustfmt line length
    - fsm.rs: collapse two-line let binding to one line per rustfmt
    - telemetry.rs: reformat rebuild_graph_points extend() calls per rustfmt
    [fsm.rs, telemetry.rs]
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2026-05-08 feat(ui): animated loading screen with staged boot progress
    Replace the static loading_screen.raw splash with a Ratatui-driven
    loading sequence that reflects real boot stages:
    - connecting wifi... (20%)
    - putting on hat... (55%, only when MQTT enabled)
    - heating up the machine... (85%)
    - waiting for machine... (100%, frozen until first UART frame)
    Each stage shows the rat barista image in the upper portion of the
    screen (rendered via render_image), version number in the top-right
    corner, and a yellow Gauge bar in the bottom strip.
    setup.rs: split init_networking into init_wifi + init_mqtt so the
    terminal can be created before networking and frames can be drawn
    between stages. Removed load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
    [app.rs, fsm.rs, global_state.rs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]
2026-05-08 feat(ux): single-button navigation, remove Main screen
    Replace two-button scheme with one button (GPIO32):
    - Short press: toggle Dashboard ↔ Graphs
    - Long press: toggle Debug screen (accessible at any time)
    Remove the Main/Rat screen — it was purely decorative.
    Dashboard is now the default screen.
    - button.rs: remove Button2 and Both variants
    - screens/screen.rs: remove Main, default → Dashboard, next() toggles two screens
    - screens/rat.rs: delete file
    - screens/mod.rs: remove rat module
    - state/fsm.rs: simplify handle_button_press, fix DebugScreen fallback, update tests
    - app.rs: remove Rat dispatch, simplify render_image (connecting only), add has_telemetry()
    - setup.rs: r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
    [app.rs, fsm.rs, setup.rs]
2026-05-08 docs: update hardware.md for single-button, fix unused Ets import
    [setup.rs]
2026-05-09 feat(setup): add minimum stage delay for loading transitions
    Introduce a `min_stage_delay` helper that ensures each loading stage
    is displayed for at least 800ms before advancing. This prevents
    stages from flashing by too quickly when initialization completes
    near-instantly.
    [setup.rs]
2026-05-09 feat(ux): allow backlight toggle via short press during loading
    During the loading phase (before the first UART telemetry frame
    arrives), short button presses had no effect. This change repurposes
    the short press to manually toggle the backlight on/off while the
    device is still initializing.
    - Add `backlight_on: bool` field to `GlobalAppState` (defaults to true)
    - In `handle_button_press`, short press during loading toggles
    `backlight_on` instead of being silently dropped
    - Move `last_activity_at` update to after the loading guard so it is
    only set during normal operation
    - Update `backlight_active` to respect `backlight_on` while loading,
    falling back to the existing timeout logic on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
    [app.rs, fsm.rs, global_state.rs]
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2026-05-11 refactor(state): remove auto-screen-switching and add ShotAborted event
    Replace the timed auto-return-to-screen logic (screen_before_extraction,
    return_to_screen_at, EXTRACTION_RETURN_DELAY, tick()) with a simpler
    model where navigation is fully manual.
    Introduce ShotAborted for pump runs shorter than 15 s (rinse/post-heat
    kick), keeping last_extraction_duration intact so a real shot's timer
    is not overwritten by a brief pump cycle.
    - Remove AppStateMachine::tick() and its call in app.rs
    - Drop screen_before_extraction / return_to_screen_at state fields
    - Add ShotAborted { duration } variant to AppEvent and telemetry
    - Emit ShotAborted instead of ShotEnded when duration < MIN_SHOT_SECS
    - H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
    [app.rs, fsm.rs, global_state.rs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]
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2026-05-11 feat(debug): add hint line and fix screen navigation behavior
    Add a "Long press to exit debug screen" hint at the bottom of the
    debug screen layout to improve UX discoverability.
    Fix terminal clear only triggering when transitioning from the loading
    screen to the debug screen, preventing unnecessary screen flashes on
    other transitions.
    Prevent short button presses from cycling screens while on the debug
    screen, ensuring only long press can exit the debug view.
    [debug.rs, fsm.rs, setup.rs]
2026-05-11 perf(graph): throttle graph sampling to 1 Hz with 5-minute window
    Replace push_triple with push_sample and a 1-second interval gate.
    Previously every telemetry frame pushed each value three times to
    smooth braille charts; now a single sample is recorded at most once
    per second, tracked via last_graph_sample_at on MachineState.
    The 300-point buffer now represents a true 5-minute rolling window
    instead of ~100 frames of triple-duplicated data.
    [fsm.rs, telemetry.rs]
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2026-05-16 fix: Wi-Fi/MQTT reconnection and connection event logging
    Wi-Fi dropped silently and permanently: status showed Connected
    forever while RSSI returned None and MQTT hung in Connecting.
    - Poll Wi-Fi health every 10s via RSSI; emit WifiStatusChanged on
    transitions so the debug screen reflects real state
    - Attempt wifi.connect() (non-blocking ESP-IDF call) every 15s while
    disconnected so the stack re-associates when the AP comes back
    - Replace stale boot-time IP with live netif query in DeviceInfoUpdated
    - Re-subscribe to cup_counter MQTT topic on every Connected event so
    the subscription survives reconnects (was lost on broker drop/restore)
    - Log Wi-Fi Connected/Disconnected and MQTT Con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
    [fsm.rs, setup.rs]
2026-05-16 style: fix rustfmt formatting in setup.rs and fsm.rs
    https://claude.ai/code/session_01QexXH2asfZeW8wpTA35Ttn
    [fsm.rs, setup.rs]
2026-05-17 feat: add telemetry age tracking and improve debug screen
    - Add `last_telemetry_age_s` field to `DeviceInfo` — seconds since the
    last UART frame; populated in both device and simulator setups via
    new `MaraUiApp::last_uart_frame_at()` trait method
    - Include `last_telemetry_age_s` in MQTT status payload for Home
    Assistant automations (node-red bridge updated accordingly)
    - Debug screen: format uptime as `1d2h30m` instead of raw seconds;
    show live telemetry age as `rx=Xs` alongside ip/heap
    - Simulator: append `-sim` suffix to MQTT client ID to avoid session
    conflicts when device and simulator connect simultaneously
    [app.rs, debug.rs, fsm.rs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]
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2026-05-27 refactor: apply full codebase code review cleanups
    - Remove dead MachineState::last_update field (set but never read)
    - Remove GlobalAppState::new() that only delegated to Default::default()
    - Fix redundant `as u64` casts on Duration::as_secs() in fsm tests
    - Fix bool assertion anti-patterns (assert_eq!(x, true) → assert!(x))
    - Add expect() message to bare unwrap() in handle_telemetry_frame
    - Extract const Style values in dashboard.rs to eliminate per-render
    Style::new() constructions (compile-time folded)
    - Deduplicate json_opt_num/json_opt_str helpers in fsm.rs, collapsing
    six repeated map().unwrap_or_else(|| "null") patterns
    - Add [lints.clippy] section to Cargo.toml to catch future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
    [fsm.rs, global_state.rs, telemetry.rs]
2026-05-27 style: fix rustfmt formatting
    [fsm.rs]
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2026-05-31 fix(hardware): update creation dates in Gerber files to reflect latest modifications
    [maratui-B_Cu.gbr, maratui-B_Mask.gbr, maratui-B_Silkscreen.gbr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]
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2026-06-03 refactor(home-assistant): move HA state topics under device prefix
    State updates now publish to `{prefix}/ha/{id}` (e.g. `mara/ha/mode`,
    `mara/ha/boiler_now`) instead of `homeassistant/sensor/maratui_*/state`.
    Discovery configs are unchanged — `homeassistant/*/config` still points
    to the correct state_topic, now under the device prefix.
    Adds `GlobalAppState::mqtt_topic_prefix` (set on init from AppConfig) so
    state-publishing functions have access to the prefix without needing it
    passed as a parameter at every call site.
    [app.rs, global_state.rs, setup.rs]
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2026-06-18 fix(display): correct display orientation to LandscapeFlipped
    [setup.rs]
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2026-06-24 fix(render): clear display and reset graphs on new telemetry session
    Addresses #30. The render loop relied solely on Ratatui's diff rendering
    and only cleared the terminal twice (entering Debug from loading, and on
    the first telemetry frame). Any display pixel corrupted by a transient SPI
    glitch was therefore never repaired, so artifacts accumulated until reboot.
    Introduce a session model: when telemetry resumes after the machine has
    been offline (no UART frame for MACHINE_OFFLINE_TIMEOUT = 30s) or on the
    first frame, treat it as a new session and request a full terminal clear,
    which heals accumulated artifacts. The clear is now driven by a
    `needs_terminal_clear` flag on GlobalAppState that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
    [app.rs, fsm.rs, global_state.rs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]
2026-06-28 fix(debug): remove leading spaces in telemetry display format
    [debug.rs]
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
